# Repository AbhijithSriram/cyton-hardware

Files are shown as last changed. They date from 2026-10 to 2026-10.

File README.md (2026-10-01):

# OpenBCI Cyton — self-fabricated board, complete record

A self-fabricated **OpenBCI Cyton V3 (32-bit)** — ordered from JLCPCB from the open
hardware files, flashed over ICSP, and made wireless with a **Seeed XIAO ESP32C3** bridge
in place of the obsolete RFD22301 radio that was never populated.

This repo is the whole record: the order files, the firmware, the bring-up, every mistake
made getting there, the software stack that records from it, and the EEG it has recorded.

| | |
|---|---|
| **Board** | OpenBCI Cyton V3, PIC32MX250F128B + ADS1299IPAG, 8 channels @ 250 SPS |
| **Firmware** | OpenBCI_32bit_Library v3.1.5, built with `board.beginDebug()` |
| **Link** | Cyton `D11`/`D12` → XIAO ESP32C3 → WiFi TCP `192.168.4.1:3000` → Flask |
| **Proven** | ADS1299 ID `0x3E`, test signal ±3.74 mV (0.3 % error), noise floor ±1 µV, 250 pkt/s with 0 malformed |
| **Recorded** | Real EEG on 2 frontal channels — alpha blocks and motor execution |

**Start here:** [`docs/CYTON_BRINGUP.md`](docs/CYTON_BRINGUP.md) — the full technical
record, fabrication through live streaming. §11 is the troubleshooting catalogue: 13 traps,
each with the symptom that identifies it.

---

## Map

| Folder | Contents |
|---|---|
| `docs/` | The bring-up document. Wiring guides for the [frontal/Muse-comparison montage](docs/WIRING-cyton-muse-athena.md) and for [motor imagery](docs/WIRING-motor-imagery.md). Electrode [research](docs/Electrode_Research.md) and [decision](docs/ELECTRODE_DECISION.md). |
| `hardware/` | What the board was built from: `gerbers/` (the set actually sent out), `bom/` (BOM + JLCPCB CPL), `quotes/` (JLCPCB, Robu, LionCircuits), `component-selection/`, `reference/` (schematic, DesignSpark source, photos). |
| `firmware/cyton/` | The exact sketch flashed to the PIC32 — `DefaultBoard` with the one changed line, `board.beginDebug()` — plus the hex the IDE built. |
| `firmware/bridge/` | `CytonWiFiBridge.ino`, the XIAO ESP32C3 UART↔TCP bridge. Its header comment is the wiring reference. |
| `firmware/images/` | `CytonDebug-with-bootloader.hex` — the merged bootloader + application image on the board right now. |
| `firmware/tools/` | `merge-hex.ps1` (Intel HEX merger with overlap detection), `listen-cyton.ps1` (serial listener that recognises the ADS1299 ID). |
| `software/` | The Flask server and web UI, the CLI client, the cue protocols, a fake bridge for working with no hardware, and `recordings/`. |
| `logs/` | The first serial capture taken off the board. |
| `vendor/`, `mechanical/` | Upstream clones and headset STLs. On disk, **git-ignored**, pinned in [`VENDOR.md`](VENDOR.md). |

## Running it

Join the bridge's WiFi (`CytonBridge`, the XIAO is always `192.168.4.1`), then:

```bash
python software/cyton_server.py
```

Open <http://127.0.0.1:5000>, press **b** to start streaming, and pick a protocol from the
experiment list. Recordings land in `software/recordings/` as CSV with a `phase` column on
every row, plus an `-events.csv` giving each cue onset as an absolute **sample index**.

No hardware attached? Two terminals:

```bash
python software/fake_bridge.py
python software/cyton_server.py --host 127.0.0.1
```

## Electrodes, as currently wired

Two channels of 3M Ag/AgCl ECG gel patches. Electrodes go to the **N** pins — the P side is
already tied to SRB2 internally.

| Patch | Position | PL1 pin | Channel |
|---|---|---:|---|
| 1 | AF7, left forehead | 21 | ch1 (`1N`) |
| 2 | AF8, right forehead | 19 | ch2 (`2N`) |
| 3 | Fpz, centre forehead | 23 | `SRB2` — reference |
| 4 | Mastoid or earlobe | 5 | `BIAS` — not optional |

Channels 3–8 read ±187500 µV because nothing is wired to them. Full detail, skin prep and
test protocol: [`docs/WIRING-cyton-muse-athena.md`](docs/WIRING-cyton-muse-athena.md).

## What is not documented

Honest gaps, listed in `docs/CYTON_BRINGUP.md` §12.4: the **battery and power wiring**
(spec, connector, charging, how SW2's missing switch is bridged), the **physical assembly
record** for the hand-soldered PL1 header and the XIAO hookup, and the **alpha ratio
comparison against the Muse**, which has recordings but no written result.

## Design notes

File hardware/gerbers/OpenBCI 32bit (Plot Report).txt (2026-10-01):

Plot Report
-----------

Report Written:     22:28 Thursday, July 02, 2026
Design Path:        C:\Users\abhij\Desktop\NeuroRehab\OpenBCI\OpenBCI Cyton Designs\OpenBCI 32bit.pcb
Design Title:       
Created:            7/31/2013 8:13:11 AM
Last Saved:         6/20/2017 11:40:16 PM
Editing Time:       116262 min
Units:              thou (precision 0)

Device Settings
===============

Gerber Settings
===============

Gerber Format: RS-274-X
    Leading zero suppression.
    G01 assumed throughout.
    Line termination <*> <CR> <LF>.
    3.5 format absolute inches.

    Format commands defined in Gerber file.
    Aperture table defined in Gerber file.
    Hardware arcs allowed.

Drill Settings
==============

    Excellon Format 2
    Format 3.5 absolute in mm.
    Zero suppression Leading

Plots Output
============

    Plot Job: "C:\Users\abhij\Desktop\NeuroRehab\OpenBCI\OpenBCI Cyton Designs\OpenBCI 32bit.mop"

Gerber Output
=============

C:\Users\abhij\Desktop\NeuroRehab\OpenBCI\OpenBCI Cyton Designs\OpenBCI 32bit - Top Silkscreen.gbr

    Layers:
    ------------------
    Top Silkscreen

    D-Code Shape  (thou)
    -----------------------
    D10    Round 5.00
    D11    Round 3.00
    D12    Round 1.00
    D13    Round 10.00
    D14    Round 8.00
    D15    Round 6.00

Gerber Output
=============

C:\Users\abhij\Desktop\NeuroRehab\OpenBCI\OpenBCI Cyton Designs\OpenBCI 32bit - Top Copper.gbr

    Layers:
    --------------
    Top Copper

    D-Code Shape  (thou)
    ----------------------------------------------
    D10    Round 5.00
    D13    Round 10.00
    D16    Round 15.00
    D17    Round 20.00
    D18    Round 32.00
    D19    Round 30.00
    D70    Round 40.00
    D71    Rectangle 11.81 X 47.24
    D20    Rectangle 11.81 X 47.24  Rotation 90
    D21    Rectangle 24.00 X 24.00
    D22    Square 63.00
    D23    Rectangle 24.00 X 24.00  Rotation 90
    D24    Rectangle 17.00 X 72.00  Rotation 90
    D25    Rectangle 39.40 X 43.30
    D26    Rectangle 39.40 X 43.30  Rotation 90
    D27    Rectangle 55.00 X 71.00
    D28    Rectangle 26.00 X 42.00
    D29    Square 60.00
    D72    Rectangle 12.00 X 20.00  Rotation 90
    D73    Rectangle 12.00 X 20.00
    D74    Rectangle 16.00 X 35.00
    D75    Square 60.00  Rotation 45
    D76    Rectangle 18.00 X 46.00  Rotation 90
    D77    Round 36.00
    D78    Rectangle 39.37 X 42.91

Gerber Output
=============

C:\Users\abhij\Desktop\NeuroRehab\OpenBCI\OpenBCI Cyton Designs\OpenBCI 32bit - Documentation.gbr

    Layers:
    -----------------
    Documentation

    D-Code Shape  (thou)
    -----------------------
    D10    Round 5.00

Gerber Output
=============

C:\Users\abhij\Desktop\NeuroRehab\OpenBCI\OpenBCI Cyton Designs\OpenBCI 32bit - Top Solder Mask.gbr

    Layers:
    -------------------
    Top Solder Mask

    D-Code Shape  (thou)
    ----------------------------------------------
    D79    Round 138.00
    D80    Rectangle 17.81 X 53.24
    D81    Rectangle 17.81 X 53.24  Rotation 90
    D82    Rectangle 30.00 X 30.00
    D83    Square 69.00
    D84    Rectangle 30.00 X 30.00  Rotation 90
    D85    Rectangle 23.00 X 78.00  Rotation 90
    D86    Rectangle 45.40 X 49.30
    D87    Rectangle 45.40 X 49.30  Rotation 90
    D88    Rectangle 61.00 X 77.00
    D89    Rectangle 32.00 X 48.00
    D90    Square 66.00
    D91    Rectangle 18.00 X 26.00  Rotation 90
    D92    Rectangle 18.00 X 26.00
    D93    Rectangle 22.00 X 41.00
    D94    Square 66.00  Rotation 45
    D95    Rectangle 24.00 X 52.00  Rotation 90
    D96    Round 42.00
    D97    Rectangle 45.37 X 48.91

Gerber Output
=============

C:\Users\abhij\Desktop\NeuroRehab\OpenBCI\OpenBCI Cyton Designs\OpenBCI 32bit - Top Paste Mask.gbr

    Layers:
    ------------------
    Top Paste Mask

    D-Code Shape  (thou)
    ----------------------------------------------
    D29    Square 60.00
    D98    Rectangle 8.81 X 44.24
    D99    Rectangle 8.81 X 44.24  Rotation 90
    D100   Rectangle 21.00 X 21.00
    D101   Rectangle 21.00 X 21.00  Rotation 90
    D102   Rectangle 14.00 X 69.00  Rotation 90
    D103   Rectangle 36.40 X 40.30
    D104   Rectangle 36.40 X 40.30  Rotation 90
    D105   Rectangle 52.00 X 68.00
    D106   Rectangle 23.00 X 39.00
    D107   Rectangle 9.00 X 17.00  Rotation 90
    D108   Rectangle 9.00 X 17.00
    D109   Rectangle 13.00 X 32.00
    D110   Rectangle 15.00 X 43.00  Rotation 90
    D111   Rectangle 36.37 X 39.91

Gerber Output
=============

C:\Users\abhij\Desktop\NeuroRehab\OpenBCI\OpenBCI Cyton Designs\OpenBCI 32bit - Layer 2 Copper.gbr

    Layers:
    ------------------
    Layer 2 Copper

    D-Code Shape  (thou)
    -----------------------------------
    D10    Round 5.00
    D13    Round 10.00
    D16    Round 15.00
    D18    Round 32.00
    D29    Square 60.00
    D75    Square 60.00  Rotation 45
    D77    Round 36.00

Gerber Output
=============

C:\Users\abhij\Desktop\NeuroRehab\OpenBCI\OpenBCI Cyton Designs\OpenBCI 32bit - Layer 3 Copper.gbr

    Layers:
    ------------------
    Layer 3 Copper

    D-Code Shape  (thou)
    -----------------------------------
    D10    Round 5.00
    D16    Round 15.00
    D18    Round 32.00
    D29    Square 60.00
    D75    Square 60.00  Rotation 45
    D77    Round 36.00

Gerber Output
=============

C:\Users\abhij\Desktop\NeuroRehab\OpenBCI\OpenBCI Cyton Designs\OpenBCI 32bit - Bottom Copper.gbr

    Layers:
    -----------------
    Bottom Copper

    D-Code Shape  (thou)
    -----------------------------------------------
    D10    Round 5.00
    D13    Round 10.00
    D14    Round 8.00
    D16    Round 15.00
    D17    Round 20.00
    D18    Round 32.00
    D19    Round 30.00
    D70    Round 40.00
    D21    Rectangle 24.00 X 24.00
    D23    Rectangle 24.00 X 24.00  Rotation 90
    D25    Rectangle 39.40 X 43.30
    D26    Rectangle 39.40 X 43.30  Rotation 90
    D29    Square 60.00
    D75    Square 60.00  Rotation 45
    D76    Rectangle 18.00 X 46.00  Rotation 90
    D77    Round 36.00
    D78    Rectangle 39.37 X 42.91
    D112   Rectangle 23.62 X 47.24  Rotation 90
    D113   Rectangle 21.65 X 47.24
    D114   Rectangle 23.62 X 47.24
    D115   Rectangle 39.37 X 42.91  Rotation 90
    D116   Square 63.00  Rotation 45
    D117   Rectangle 10.00 X 27.56
    D118   Rectangle 32.00 X 132.00  Rotation 90
    D119   Rectangle 27.00 X 63.00  Rotation 135
    D120   Rectangle 47.00 X 87.00  Rotation 135
    D121   Rectangle 55.00 X 63.00  Rotation 45
    D122   Rectangle 47.00 X 63.00  Rotation 135
    D123   Rectangle 59.00 X 134.00
    D124   Rectangle 39.00 X 138.00
    D125   Rectangle 28.00 X 59.00  Rotation 90
    D126   Rectangle 32.00 X 39.00
    D127   Rectangle 55.00 X 55.00  Rotation 135

Gerber Output
=============

C:\Users\abhij\Desktop\NeuroRehab\OpenBCI\OpenBCI Cyton Designs\OpenBCI 32bit - Bottom Silkscreen.gbr

    Layers:
    ---------------------
    Bottom Silkscreen

    D-Code Shape  (thou)
    -----------------------
    D10    Round 5.00
    D11    Round 3.00
    D14    Round 8.00
    D15    Round 6.00

Gerber Output
=============

C:\Users\abhij\Desktop\NeuroRehab\OpenBCI\OpenBCI Cyton Designs\OpenBCI 32bit - Bottom Solder Mask.gbr

    Layers:
    ----------------------
    Bottom Solder Mask

    D-Code Shape  (thou)
    -----------------------------------------------
    D79    Round 138.00
    D82    Rectangle 30.00 X 30.00
    D84    Rectangle 30.00 X 30.00  Rotation 90
    D86    Rectangle 45.40 X 49.30
    D87    Rectangle 45.40 X 49.30  Rotation 90
    D90    Square 66.00
    D94    Square 66.00  Rotation 45
    D95    Rectangle 24.00 X 52.00  Rotation 90
    D96    Round 42.00
    D97    Rectangle 45.37 X 48.91
    D128   Rectangle 29.62 X 53.24  Rotation 90
    D129   Rectangle 27.65 X 53.24
    D130   Rectangle 29.62 X 53.24
    D131   Rectangle 45.37 X 48.91  Rotation 90
    D132   Square 69.00  Rotation 45
    D133   Rectangle 16.00 X 33.56
    D134   Rectangle 38.00 X 138.00  Rotation 90
    D135   Rectangle 33.00 X 69.00  Rotation 135
    D136   Rectangle 53.00 X 93.00  Rotation 135
    D137   Rectangle 61.00 X 69.00  Rotation 45
    D138   Rectangle 53.00 X 69.00  Rotation 135
    D139   Rectangle 65.00 X 140.00
    D140   Rectangle 45.00 X 144.00
    D141   Rectangle 34.00 X 65.00  Rotation 90
    D142   Rectangle 38.00 X 45.00
    D143   Rectangle 61.00 X 61.00  Rotation 135

Gerber Output
=============

C:\Users\abhij\Desktop\NeuroRehab\OpenBCI\OpenBCI Cyton Designs\OpenBCI 32bit - Bottom Paste Mask.gbr

    Layers:
    ---------------------
    Bottom Paste Mask

    D-Code Shape  (thou)
    -----------------------------------------------
    D75    Square 60.00  Rotation 45
    D100   Rectangle 21.00 X 21.00
    D101   Rectangle 21.00 X 21.00  Rotation 90
    D103   Rectangle 36.40 X 40.30
    D104   Rectangle 36.40 X 40.30  Rotation 90
    D110   Rectangle 15.00 X 43.00  Rotation 90
    D111   Rectangle 36.37 X 39.91
    D144   Rectangle 20.62 X 44.24  Rotation 90
    D145   Rectangle 18.65 X 44.24
    D146   Rectangle 20.62 X 44.24
    D147   Rectangle 36.37 X 39.91  Rotation 90
    D148   Rectangle 7.00 X 24.56
    D149   Rectangle 29.00 X 129.00  Rotation 90
    D150   Rectangle 24.00 X 60.00  Rotation 135
    D151   Rectangle 44.00 X 84.00  Rotation 135
    D152   Rectangle 52.00 X 60.00  Rotation 45
    D153   Rectangle 44.00 X 60.00  Rotation 135
    D154   Rectangle 56.00 X 131.00
    D155   Rectangle 36.00 X 135.00
    D156   Rectangle 25.00 X 56.00  Rotation 90
    D157   Rectangle 29.00 X 36.00
    D158   Rectangle 52.00 X 52.00  Rotation 135

Gerber Output
=============

C:\Users\abhij\Desktop\NeuroRehab\OpenBCI\OpenBCI Cyton Designs\OpenBCI 32bit - Gerber Drill Data - [Through Hole].gbr

    Layers:
    ------------------
    [Through Hole]

    D-Code Shape  (thou)
    -----------------------
    D159   Round 16.00
    D160   Round 185.00
    D161   Round 35.00
    D162   Round 36.00

NC Drill Output
===============

C:\Users\abhij\Desktop\NeuroRehab\OpenBCI\OpenBCI Cyton Designs\OpenBCI 32bit - NC Drill Data - [Through Hole].drl

    Output:
    ---------------------------
    Plated Round Drill Holes
    Plated Slots

    Tool  Size           Count   ID
    --------------------------------------
    T001  0.01600 inches 105   A
    T002  0.03500 inches 44    C
    --------------------------------------
    Total                149
    --------------------------------------

C:\Users\abhij\Desktop\NeuroRehab\OpenBCI\OpenBCI Cyton Designs\OpenBCI 32bit - NC Drill Data - [Through Hole] (Unplated).drl

    Output:
    -----------------------------
    Unplated Round Drill Holes
    Unplated Slots

    Tool  Size           Count   ID
    --------------------------------------
    T001  0.03500 inches 2     D
    T002  0.03600 inches 2     E
    T003  0.18500 inches 4     B
    --------------------------------------
    Total                8
    --------------------------------------

Gerber Output
=============

C:\Users\abhij\Desktop\NeuroRehab\OpenBCI\OpenBCI Cyton Designs\OpenBCI 32bit - Drill Ident Drawing - [Through Hole].gbr

    Layers:
    ------------------
    [Through Hole]

Drill Ident Drawing
===================

    Drill Plated Size Shape ID
    -----------------------------------
    16    Y      100  Round A
    185          100  Round B
    35    Y      100  Round C
    35           100  Round D
    36           100  Round E

    D-Code Shape  (thou)
    -----------------------
    D10    Round 5.00
    D163   Round 100.00

Gerber Output
=============

C:\Users\abhij\Desktop\NeuroRehab\OpenBCI\OpenBCI Cyton Designs\OpenBCI 32bit - Board Outline.gbr

    Layers:
    ------------------
    Board Outlines

    D-Code Shape  (thou)
    -----------------------
    D10    Round 5.00

End Of Report.

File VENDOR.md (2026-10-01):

# Upstream dependencies

Four upstream trees are used by this project. All are public, all are pinned to a known
commit, and none of them are tracked here — `vendor/` and `mechanical/` are git-ignored, so
a clone of this repo is small and contains only work that cannot be downloaded again.

Everything in those trees that was **not** upstream — the regenerated Gerbers, the JLCPCB
BOM and CPL, the quotes, the component-selection PDFs — was lifted out into `hardware/`
and **is** tracked here. Nothing irreplaceable sits behind a `.gitignore`.

| Path on disk | Upstream | Pinned at | Why it is kept |
|---|---|---|---|
| `vendor/openbci-v3-hardware/` | <https://github.com/OpenBCI/V3_Hardware_Design_Files> | `6bce559` (2023-02-06) | Schematic, PCB, upstream Gerbers and BOM/CPL. Two files locally modified — see below |
| `vendor/openbci-v3-hardware/OpenBCI_Cyton_Library/` | <https://github.com/OpenBCI/OpenBCI_Cyton_Library> | `24e1c42` (2025-07-24) | v3.1.5 — the firmware source that was compiled and flashed |
| `vendor/openbci-v3-hardware/PIC32-avrdude-bootloader/` | <https://github.com/chipKIT32/PIC32-avrdude-bootloader> | `95cf5d9` (2024-02-08) | `BootloadersCurrent-hex/UDB32_MX2_DIP.hex` is the bootloader half of the flashed image |
| `mechanical/ultracortex-upstream/` | <https://github.com/OpenBCI/Ultracortex> | `338b52b` (2022-09-29) | Headset mechanicals. Only `Mark_IV` is checked out; the clone's index is empty |

`vendor/PIC32-avrdude-bootloader-master/` plus its zip is an older, separate download of
the same bootloader. Kept because the flashing was actually done from that copy.

`mechanical/a1-mini-prints/` is **not** upstream — those are the Bambu A1 Mini plates and
the Cyton case that were printed. 2.6 MB. Git-ignored with the rest of `mechanical/`; to
track them instead, drop the `/mechanical/` line from `.gitignore` and re-add.

## Restoring any of them

```bash
# hardware design files (the parent tree)
git clone https://github.com/OpenBCI/V3_Hardware_Design_Files.git vendor/openbci-v3-hardware
git -C vendor/openbci-v3-hardware checkout 6bce559

# Cyton firmware library, nested inside it (and installed for the IDE at
# Documents/Arduino/libraries/OpenBCI_32bit_Library)
git clone https://github.com/OpenBCI/OpenBCI_Cyton_Library.git \
          vendor/openbci-v3-hardware/OpenBCI_Cyton_Library
git -C vendor/openbci-v3-hardware/OpenBCI_Cyton_Library checkout 24e1c42

# chipKIT bootloader
git clone https://github.com/chipKIT32/PIC32-avrdude-bootloader.git \
          vendor/openbci-v3-hardware/PIC32-avrdude-bootloader
git -C vendor/openbci-v3-hardware/PIC32-avrdude-bootloader checkout 95cf5d9

# headset mechanicals
git clone https://github.com/OpenBCI/Ultracortex.git mechanical/ultracortex-upstream
git -C mechanical/ultracortex-upstream checkout 338b52b
```

The existing Ultracortex clone has a populated HEAD against an empty index, so it looks
like 686 staged deletions and only `Mark_IV` is on disk. Its pack holds every revision —
`Mark_1`, `Mark_2`, `Mark_3`, `Mark_III_Nova`, `Mark_III_Nova_REVISED`, `Mark_IV` — and one
command brings them all back without the network:

```bash
git -C mechanical/ultracortex-upstream reset --hard HEAD
```

That is what made it safe to delete `Ultracortex2/` (502 MB, a duplicate `.git` at the same
commit), `Ultracortex_Downloaded/` (175 MB, `Mark_1`–`Mark_3`) and `Ultracortex.zip`
(79 MB) on 1 October 2026. 756 MB freed, nothing lost.

## Local modifications to the hardware design files

Two tracked files in `vendor/openbci-v3-hardware/` differ from upstream. Both are copied
into `hardware/`, so a fresh clone of upstream plus this repo reproduces what was ordered:

| File in the clone | Change | Tracked copy here |
|---|---|---|
| `OpenBCI Cyton Designs/OpenBCI 32bit.pcb` | Re-saved from DesignSpark (360 KB → 395 KB) | `hardware/reference/OpenBCI 32bit.pcb` |
| `OBCI_Cyton_Plots/OBCI_V4_C (Component Positions CSV).csv` | Header rewritten to JLCPCB CPL format: `Name,Component,Side,Centre X,Centre Y,Rotation` → `Designator,Val,Layer,Mid X,Mid Y,Rotation` | `hardware/bom/CPL-OBCI_V4_C-jlcpcb-format.csv` |

## Toolchain versions

Not vendored, but the versions that worked, for the record:

| Tool | Version | Note |
|---|---|---|
| Arduino IDE | 2.x | chipKIT core for the Cyton, ESP32 core for the XIAO |
| chipKIT core | 2.1.0 | Already ships `Board_Defs.h` with 11/12 — do **not** apply the library's stale edit instruction |
| Board (Cyton) | chipKIT → OpenBCI 32 | variant `chipKIT.pic32.openbci` |
| Board (bridge) | XIAO_ESP32C3 | **USB CDC On Boot: ENABLED** — not optional |
| MPLAB X IPE | v5.35 | Flashing the merged hex with a PICkit 3.5 |

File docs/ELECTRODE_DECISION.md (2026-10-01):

# Electrode & Headset Decision — NeuroRehab

**Working document for the headset design. Two viable paths, laid out with costs, setup, and the reasoning behind each.**

Context: the Cyton is built and streaming (see `CYTON_BRINGUP.md`). The remaining hardware question is what touches the scalp. This is written as a decision aid, not a conclusion — the recommendation shifts depending on whether the target is a research rig or a patient-facing rehab product.

> 💰 All prices are **estimates in INR**, current as of writing. OpenBCI prices are from their store; "generic" prices assume AliExpress / IndiaMART sourcing. **Add shipping and customs for anything imported** — a real factor, and the same one that drove the decision to fabricate the Cyton at JLCPCB rather than buy it.

---

## 1. The montage is already fixed

This is not an open question. From `Neuro-Rehab-git/src/run_ablation.sh`:

```bash
# Simulates testing 8-channel consumer EEG hardware (e.g. ADS1299)
CHANNELS="C3 Cz C4 FC3 FC4 CP3 CP4"
```

The same seven appear in `cache_foundation.py` and `cache_openbmi.py`. A 5-channel subset (`C3, Cz, C4, CP3, CP4`) is used in `train_physionet_5ch.py` with weights at `Models/neurorehab_bci_5ch.pth`.

**Requirement: 7 scalp electrodes + 1 reference + 1 bias = 9 total.** The Cyton has 8 differential inputs, so 7 channels used, 1 spare.

Geometrically these form a **3×3 grid centred on Cz**, roughly 12 cm ear-to-ear and 8 cm front-to-back:

```
        FC3    ·    FC4
         C3   Cz    C4          all within the central third
        CP3    ·    CP4          of the scalp
```

This compactness matters later — see §5.

---

## 2. What the benchmark already tells us

From `Neuro-Rehab-git/README.md`:

| Dataset | Channels | Best model | Accuracy |
|---|---:|---|---:|
| **2B** | **3** (C3/Cz/C4) | Conformer (transfer) | **78.89%** |
| 2A | 22 | EEGNet | 78.86% |

**Three well-placed electrodes matched twenty-two.** Channel *count* is not the bottleneck, so no headset choice fails on coverage grounds. What the same table shows is where accuracy actually leaks:

- **FBCSP collapsed to 52.95%** at 3 channels — near chance. Classical methods need spatial redundancy.
- **EEGNet fell 78.86% → 70.91%** when channels were cut ("struggles when deprived of spatial electrodes").
- **Transfer learning recovered it** — Conformer, Deep4 and Inception each gained 4–6 points at low density.

> ⚠️ **Architecture note:** `Models/neurorehab_bci_5ch_eegnet.txt` exists. By this benchmark, EEGNet is the *weakest* architecture in exactly the low-channel regime the Cyton puts you in. Conformer-with-transfer is the strongest. Worth revisiting before deployment.

Since coverage is solved, the headset decision reduces to two variables: **placement repeatability** and **contact impedance**.

---

## 3. Option A — Wet: textile 10-20 cap + gold cup electrodes

The research-standard approach.

### 3.1 Bill of materials

| Item | Qty | OpenBCI | Generic | Notes |
|---|---:|---:|---:|---|
| Textile 10-20 EEG cap | 1 | — | ₹2,000–5,000 | **Must have 10-10 markings** — FC3/FC4/CP3/CP4 are not in the 19-site 10-20 set |
| Gold cup electrodes | 10 | ₹4,400 | ₹1,500–3,000 | ₹150–300 each generic vs ~₹440 from OpenBCI |
| Ten20 conductive paste (228 g) | 1 | — | ₹1,200–2,000 | The actual conductor |
| NuPrep abrasive gel (114 g) | 1 | — | ₹700–1,200 | Skin prep — matters more than people expect |
| Blunt-tip syringes | few | — | ₹300 | For getting paste under hair |
| Measuring tape + skin pencil | 1 | — | ₹200 | For nasion–inion measurement |
| Gauze, alcohol wipes | — | — | ₹500 | Consumable |
| **Total** | | | **₹6,400–12,200** | |

**Not needed:** OpenBCI's ₹3,900 *Header Pin to Touch Proof Adapter*. That's for DIN 1.5 mm electrodes; gold cups terminating in header pins plug into the Cyton directly.

### 3.2 Setup procedure (~15–20 min per session)

1. Measure **nasion → inion** and **left preauricular → right preauricular**. Cz is at 50% of both.
2. Select cap size by head circumference; seat it with the cap's Cz marker on the measured Cz.
3. For each of 9 sites: part the hair, abrade lightly with NuPrep on a cotton bud.
4. Fill the gold cup with Ten20, press onto the scalp through the cap hole, seat until the paste bridges.
5. Reference and bias go on the **mastoids or earlobes** (no hair, easy contact).
6. Verify impedance on every channel before starting.
7. Afterwards: patient washes their hair; cap is washed and dried.

### 3.3 Why it's the strongest signal

- **Impedance in single-digit kΩ** versus hundreds of kΩ dry. Mu (8–13 Hz) and beta (13–30 Hz) ERD are small effects, and the Cyton's ±1 µV noise floor is only meaningful if the electrode isn't the dominant noise source.
- **Precise, repeatable placement.** Positions are *measured* from anatomical landmarks, so they're the same today and next month. This is what makes a model trained once transfer across sessions.
- **Matches the training data.** PhysioNet and OpenBMI were recorded at exact 10-10 coordinates. Placement error is distribution shift.
- **Motion tolerance.** Paste maintains contact through small head movements.

### 3.4 Why it fails as a rehab product

| Problem | Consequence |
|---|---|
| 15–20 min setup, every session | A rehab programme is *many* sessions. This is a dropout cause, not an inconvenience. |
| Patient leaves with gel in their hair | Dignity issue. Requires a shower after every session. |
| Cap must be washed and dried between patients | Kills clinic turnaround; you'd need several caps in rotation. |
| Requires a trained operator | Not something a caregiver does at home. |
| Long static sitting during application | Hard for hemiparetic patients. |

**Verdict: correct for collecting training data and for validation. Wrong for the product.**

---

## 4. Option B — Dry: comb electrodes

### 4.1 Why this is right for neurorehab

The properties that make wet electrodes better in a lab are precisely what make them unusable in a clinic:

| | Wet | Dry |
|---|---|---|
| Setup per session | 15–20 min | **~2–3 min** |
| Patient leaves with | Gel in hair | **Nothing** |
| Between patients | Wash + dry cap | **Alcohol wipe** |
| Who can apply it | Trained operator | **A caregiver, after a demo** |
| Repeat sessions over weeks | High friction | **Low friction** |

For stroke rehabilitation — repeated sessions over weeks or months, patients with hemiparesis and possible cognitive load, applied by clinic staff or family — **ease of donning dominates absolute signal quality.**

### 4.2 What makes it actually work: per-session calibration

The usual objection to dry electrodes is that placement and impedance vary between sessions, so a model trained once doesn't transfer.

**The pipeline already doesn't assume that.** `benchmark_results_final.csv` contains `n_calib_trials` of 10/15/20/27 and a full `3_adaptation` phase. Per-subject calibration is already the architecture.

A short calibration at the start of each session absorbs that day's placement and contact quality into the model. Session-to-session variability stops being an engineering problem and becomes a two-minute step the patient does while getting settled.

> **Dry electrodes + per-session calibration is a legitimate product architecture.** It costs a few accuracy points and buys a device people will actually use.

### 4.3 Bill of materials

| Item | Qty | OpenBCI | Generic / DIY | Notes |
|---|---:|---:|---:|---|
| Dry comb electrodes | 9 + spares | ₹4,900 (30-pack) | — | ≈₹163 each — reasonable. Designed for the Ultracortex node holder |
| *or* EEG Snap Electrodes (metal comb) | 5-pack | ₹3,000 | — | Needs snap cables (₹5,400) — **more expensive overall** |
| Ear-clip electrodes (ref + bias) | 2 | — | ₹500–1,500 | Earlobes/mastoids have no hair — clips beat combs here |
| Octabolts + electrode holders | 9 | — | **3D printed** | STLs already in `Ultracortex/.../M4 Hardware/` |
| Compression springs | 9 | — | ₹300 | For the spring-loaded node assembly |
| M3 screws / nuts / heat inserts | — | — | ₹400 | |
| Filament (PETG or PLA) | ~150 g | — | ₹300 | Band + holders |
| Silicone-jacketed wire, 26–28 AWG | ~5 m | — | ₹500 | Electrode → Cyton |
| Dupont / header connectors | — | — | ₹300 | To PL1 |
| 13×2 header for PL1 | 1 | — | ₹100 | ⚠️ **Count the pads first** — README says 11×2, CPL says `26WDP` |
| **Total** | | | **≈₹7,300–9,000** | |

**Comparable up-front cost to wet.** The real difference is **per-session consumables (zero vs paste + prep gel) and time (2 min vs 20 min).** Over a rehab programme, that's the entire argument.

### 4.4 Setup procedure (~2–3 min per session)

1. Select band size / adjust the sliding mechanism.
2. Seat using ear-canal and nasion landmarks.
3. Tighten each Octabolt until the contact indicator (§6) goes green.
4. Run the calibration block.
5. Afterwards: wipe electrodes with alcohol.

---

## 5. The design insight: build a band, not a cage

The Ultracortex Mark IV is a full geodesic head frame reaching 35 positions from Fp to O. **You use none of the frontal, temporal, or occipital structure** — your 7 sites sit in a compact 3×3 grid over the vertex (§1).

You are carrying a whole-head exoskeleton to instrument a strip.

**Proposal: a sensorimotor band.** An arc over the vertex from ear to ear, with short forward and rearward arms reaching the FC and CP rows — roughly an "H" or cross shape.

| Benefit | Why |
|---|---|
| **Faster donning** | One axis to align, not a cage to seat |
| **Better repeatability** | Anchor on **ear canals** (coronal line through Cz) and **nasion–inion** (A–P). Those are the same landmarks a 10-20 measurement uses — arguably *more* repeatable than a lattice hole that happens to land near FC3 |
| **Lighter, less clinical** | A band reads as a headset; a cage reads as an experiment. Matters for patient acceptance |
| **Fewer sizes to stock** | The DevKit ships five frames (`08mm_Small` → `28mm_Large`). A shorter arc tolerates far more head-size variation with one adjustment mechanism |
| **Reuses existing parts** | `M4_Hardware_09_Octabolt.STL`, `M4_Hardware_09_Eholder.STL`, `M4_Hardware_07d_Node_4d.STL` are already in the Ultracortex checkout. Keep the spring-loaded comb assembly, drop the cage |

### 5.1 Caveat on Ultracortex placement accuracy

The Mark IV is a **lattice, not a 10-20 map**. The README says the frame is *"based on an average of many heads"*; you screw nodes into whichever holes land near your target. So a Mark IV position is *approximately* FC3, varying with head size and re-seating.

For C3/C4 mu-ERD that's survivable — motor cortex is a broad strip. But it isn't repeatable between sessions, which is exactly what per-session calibration exists to absorb. A landmark-referenced band reduces the problem at source rather than relying on software to fix it.

---

## 6. Contact quality becomes a product requirement

With dry electrodes, **bad contact is the failure mode**, and the clinician must see it *before* the session, not after.

Both halves already exist:

- **Firmware:** `configureLeadOffDetection(LOFF_MAG_6NA, LOFF_FREQ_31p2HZ)` runs inside `boardReset()` at every boot. The ADS1299 impedance measurement is already configured.
- **Client:** `is_railed()` in `cyton_client.py` flags `±187500 µV` — exactly what a detached or badly-seated electrode looks like.

**To build:** a per-electrode contact indicator in the web UI — green / amber / red per channel, live during donning. The clinician adjusts each Octabolt until all seven go green, then starts.

That single feature is what separates "dry electrodes work in the lab" from "dry electrodes work in a clinic."

---

## 7. Residual risks

| Risk | Notes | How to retire it |
|---|---|---|
| **Thick or dense hair** | Where dry combs genuinely struggle. No software fix. | Test early with hair types representative of actual patients — not just yours. Fallback is a little saline on the comb tips (towels off, no shower) |
| **Comfort over 30–60 min** | Spring-loaded combs press into the scalp. Fine for 10 min, potentially sore for an hour | Measure with real session lengths before finalising the mechanical design |
| **Hemiparetic patients** | May not tolerate certain head positions or be able to assist | Design for one-handed application by a caregiver |
| **Accuracy delta vs wet** | Unquantified for this hardware | Run the same subject through both — that comparison is publishable and directly answers the question |

---

## 8. Summary

| | Wet cap | Dry band |
|---|---|---|
| Up-front cost | ₹6,400–12,200 | ₹7,300–9,000 |
| Per-session consumables | Paste + prep gel | **None** |
| Setup time | 15–20 min | **2–3 min** |
| Placement repeatability | **Excellent** (measured) | Good (landmark-referenced band) |
| Impedance | **Single-digit kΩ** | Hundreds of kΩ |
| Clinic turnaround | Poor | **Excellent** |
| Patient acceptance | Poor | **Good** |
| Best for | Training data, validation, the wet-vs-dry comparison | **The product** |

**Recommendation: build the dry band for the product; keep a wet cap for collecting ground-truth training data and for measuring what dry costs you.** They are not competing options — the wet setup is the instrument you use to validate the dry one.

---

## 9. Open questions for brainstorming

1. Is the reference on **mastoid, earlobe, or Cz**? Affects both the band geometry and how the montage compares to the training data.
2. Does calibration happen **every session**, or only when contact quality degrades? Changes the patient experience meaningfully.
3. **One band size with a wide adjustment range, or two?** Affects moulding cost later.
4. Does the Cyton mount **on the band** (weight on the head) or **clip to clothing** (cable strain)?
5. Should the contact indicator be **on the device** (an LED strip the clinician can see while adjusting) rather than only in the browser?
6. Is the target **clinic-only**, or eventually **home use**? Home use raises the bar on donning simplicity considerably.
7. Retrain on **Conformer + transfer** rather than EEGNet before deployment? §2 suggests ~8 recoverable points.

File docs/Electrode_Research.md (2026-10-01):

# Domestic Indian Sourcing Guide: EEG Electrodes, Consumables & DIY Components for an ADS1299 Motor-Imagery BCI

## TL;DR
- Nearly everything needed can be sourced domestically within India — gold cup electrodes, ear clips, conductive paste, skin prep, ECG electrodes, wire, connectors, and pogo pins are all available from Indian sellers (pan-India shipping) or Chennai-based distributors, at prices well below the OpenBCI benchmarks.
- The hardest item is the multi-prong "dry comb" electrode — no true OpenBCI-style comb electrode is made or resold domestically. Best domestic option: a single-spike dry electrode from Fab.to.Lab, or DIY pogo-pin fabrication.
- For patient-contact use in a stroke-rehab BCI, prefer verified-material wet electrodes (gold/Ag-AgCl cup + paste) over DIY pogo pins, whose nickel underplate cannot be verified from Indian retailer listings — a genuine allergen-safety concern.

Every claim below is linked to its source listing where I have one. Where I could not find or re-capture a stable product URL, I've said so explicitly rather than presenting an unverified guess as fact.

---

## PRIORITY 1 — Electrodes

### 1. Dry comb EEG electrodes (multi-prong, hair-parting) — HARDEST ITEM
**Status: no domestic multi-prong comb electrode found.**

- **Benchmark for comparison:** OpenBCI's ["Dry EEG Comb Electrodes (Pack of 30)"](https://shop.openbci.com/products/dry-eeg-comb-electrodes) — $49.99 for 30 (~$1.67/electrode), silver-then-chlorided 5mm prongs. This is the multi-finger comb type you're trying to replace domestically.
- **Closest domestic ready-made item:** [Fab.to.Lab — "Disposable/Reusable Longer Spike dry EEG Electrode TDE 210 – 5mm"](https://www.fabtolab.com/fri-disposable-reusable-dry-eeg-electrode-tde-210-emg-ecg-eog-5mm) (Bangalore). Listed at ₹400/unit at qty 1, with volume breaks shown on the page (5+ → ₹125 ea, 10+ → ₹95 ea, 50+ → ₹80 ea). **This is a single 5mm spike, not a multi-prong comb** — one point of contact per electrode, not several fingers. The listing does not state electrode coating material (Ag/AgCl vs. stainless vs. gold) — unverified on the page itself.
- **Adjacent domestic product (not a comb, for context):** [Upside Down Labs — "Gold cup electrodes (Pack of 10)"](https://store.upsidedownlabs.tech/product/gold-cup-electrodes-pack-of-10/) and their [BioAmp EXG Pill kit on Amazon.in](https://www.amazon.in/Explorer-Neuroscience-Upside-Down-Labs/dp/B0B29CCPQB), which states it ships with a "dry electrode based EEG Band." Upside Down Labs is an Indian neurotech hardware company, so worth watching, but this is a fabric-band dry electrode, not a comb.
- **DIY fallback, technically documented:** [NCBI/PMC — "3D Printed Dry EEG Electrodes"](https://www.ncbi.nlm.nih.gov/pmc/articles/PMC5087423/) describes the exact 3D-printed-base-plus-conductive-pin construction method you're planning, with electrical performance data — worth reading before finalizing pin geometry.

**Assessment:** I did not find a single Indian manufacturer or reseller of a true multi-prong Ag/AgCl comb electrode across IndiaMART, TradeIndia, Amazon.in, or Indian neurotech stores. This is a negative result — inherently less certain than a positive one — so treat it as "not found in this search," not an absolute guarantee none exists.

### 2. Gold cup EEG electrodes (reusable, ~10mm cup, with lead wire)

| Supplier | Price | Link |
|---|---|---|
| Paul Medical Systems (Chennai) | ₹3,300/piece | [IndiaMART listing](https://www.indiamart.com/proddetail/eeg-electrodes-gold-cup-eeg-electrodes-eeg-disc-electrode-eeg-cup-electrodes-19125339833.html) |
| SS Medsys (New Delhi) | ₹2,200/piece | [IndiaMART listing](https://www.indiamart.com/proddetail/gold-cup-electrodes-20466577188.html) |
| Rama Industries (Mohali) | ₹4,500/set | [IndiaMART listing](https://www.indiamart.com/proddetail/eeg-cup-electrode-gold-plated-22313693655.html) |
| Unique Medical Systems (Mohali) | ₹2,500/set, **MOQ 25 electrodes** | [IndiaMART listing](https://www.indiamart.com/proddetail/eeg-electrode-gold-plated-15036018662.html) |
| Bionen (distributor, Pune) | ₹1,500/piece | [IndiaMART listing](https://www.indiamart.com/proddetail/gold-plated-eeg-electrodes-21496130662.html) |

**Connector note:** these ship with standard clinical EEG lead wires (often 1.5mm DIN touch-proof plugs); none of the listings mention Dupont/header-pin-compatible leads, so budget time to terminate/adapt the free end yourself.

**Wear caveat:** OpenBCI's own product page for their gold cup electrodes notes the electrode should be retired once the gold plating is visibly worn through, because the exposed base metal introduces galvanic noise. The same physical principle applies to any gold-plated cup regardless of manufacturer — treat these as a consumable.

### 3. Ear clip electrodes (reference/bias on earlobe/mastoid)
- I found a reference to AdInstruments South Asia India ear clip electrodes (silver, 9.5mm, 190cm leads) during search, but **could not re-capture a stable direct product URL with a confirmed price** in this pass — flagging as unverified rather than asserting a link I can't stand behind.
- Better path: message the Paul Medical Systems or SS Medsys IndiaMART listings above directly (both have "get best price" contact forms) and ask whether ear-clip leads are sold alongside their cup electrode sets — several sellers in this space bundle both but don't itemize ear clips separately on the public listing.

### 4. Disposable Ag/AgCl ECG electrodes (proposed for reference + bias positions)
- I have directional information (Chennai suppliers Micro Med Charts Mfg. Co. and Growell Technomed were named in search results at roughly ₹4–6/electrode), **but I did not retain checkable product URLs for either during this pass.** I'm not going to present those as clickable links since I can't verify them right now.
- What I can point you to directly: search "disposable ECG electrodes" on [Amazon.in](https://www.amazon.in) — bulk hydrogel Ag/AgCl electrode packs (50–100 count) are a well-established, high-turnover product category there, typically ₹3–5/electrode in bulk. I'd rather send you to search live listings than give you a specific link I can't verify is still active.

**Technical assessment (my own reasoning, not sourced from search):** Disposable Ag/AgCl ECG electrodes are well suited to the reference/bias mastoid positions. Ag/AgCl has a lower and more stable half-cell potential than gold, which is why it's the standard EEG reference material clinically; the pre-gelled adhesive gives good, stable impedance on hairless skin; and single-use is actually convenient for a reference site that needs replacing between sessions. Main practical gap: you'll need a snap-to-wire adapter, which isn't included with these.

---

## PRIORITY 2 — Consumables

### 5. Ten20 conductive paste

| Supplier | Price | Link |
|---|---|---|
| Paul Medical Systems (Chennai) | ₹1,400/packet | [IndiaMART listing](https://www.indiamart.com/proddetail/ten20-eeg-conductive-paste-16249115288.html) |
| Growell Technomed (Chennai) | Price on inquiry | [Growell Technomed product page](https://www.growelltechnomed.in/ten20-eeg-conductive-paste.htm) |
| Distributor, New Delhi | ₹1,500/piece | [IndiaMART listing](https://www.indiamart.com/proddetail/ten20-conductive-neurodiagnostic-electrode-paste-15297336988.html) |
| Distributor, Thiruvananthapuram | ₹1,300 | [Exporters India listing](https://www.exportersindia.com/product-detail/weaver-ten20-conductive-eeg-paste-6147903.htm) |
| Sonika Mediequip (Vadodara) | ₹1,850 | [TradeIndia listing](https://www.tradeindia.com/products/ten20-conductive-eeg-paste-c1753674.html) |
| Aditya Enterprise (Mumbai) | Price on inquiry | [Aditya Enterprise product page](https://www.aditya-enterprise.com/ten20-conductive-paste.html) |

Six independent listings, prices clustering ₹1,300–1,850 — good confidence in both availability and price range.

### 6. NuPrep abrasive skin prep gel

| Supplier | Price | Link |
|---|---|---|
| Paul Medical Systems (Chennai) | ₹1,200 | [Exporters India listing](https://www.exportersindia.com/product-detail/nuprep-skin-prep-gel-2791154495.htm) |
| Distributor, New Delhi (114g tube) | ₹1,200 | [IndiaMART listing](https://www.indiamart.com/proddetail/nuprep-skin-gel-114gms-tube-3088712033.html) |
| Distributor, Hyderabad (100g) | ₹1,100 | [IndiaMART listing](https://www.indiamart.com/proddetail/nuprep-skin-prep-gel-2854058023748.html) |
| RespBuy (online, pan-India) | Listed by pack size | [RespBuy product page](https://respbuy.com/product/weaver-nuprep-skin-preparation-gel-114-gms/) |
| Kardio Surgicare (New Delhi) | Price on inquiry | [Kardio Surgicare product page](https://www.kardiosurgicare.com/skin-preparing-gel.html) |

Same confidence level as Ten20 — multiple independent, consistent listings.

---

## PRIORITY 3 — DIY dry electrode build components

### 7. Gold-plated spring-loaded pogo pins / spring test probes

| Supplier | Product | Price | Link |
|---|---|---|---|
| Robokits India | Spring Test Probe Pogo Pin P75-E2 (MOQ 10pcs) | ₹21/pin | [Robokits product page](https://robokits.co.in/components/cables-connectors/spring-test-probe-pogo-pin-p75-e2-moq-10pcs) |
| Probots | P75-D2 Pogo Pin, round/crown head, PCB testing | ~₹30/pin | [Probots product page](https://probots.co.in/p75-d2-pogo-pin-with-crown-head-for-pcb-testing.html) |
| iFuture Technology | PL75-B1, 0.7mm tip, 16mm length | Priced on page | [iFuture Technology product page](https://ifuturetech.org/product/pl75-b1-0-7mm-tip-16mm-pogo-spring-test-probe-pin/) |

**Plating/nickel flag — the most important safety finding in this document.** Two independent electronics-industry sources describe how these commodity pins are actually constructed:
- [Alibaba's buying guide, "How to Choose Gold Plated Spring Probe Pins"](https://electronics.alibaba.com/buyingguides/gold-plated-spring-probe-pin-guide-what-you-actually-need) — describes the standard build as a thin gold flash over a nickel underplate over a brass or beryllium-copper barrel, presented as the *normal* spec, not an exception.
- [Metabee's "What is a Pogo Pin?" guide](https://metabee.com/blog/post/what-is-a-pogo-pin-the-comprehensive-guide-to-spring-loaded-connectors) — confirms the same gold-over-nickel-over-base-metal layering as conventional construction.

None of the three Indian retailer pages above (Robokits, Probots, iFuture) publish a plating-thickness spec or state whether their specific SKU includes a nickel barrier — I checked each page directly and this information is simply absent, so I can describe the industry-standard construction from the sources above but cannot verify the exact stack per SKU.

On the health side: nickel being a very common contact allergen is something I know from general biomedical background rather than a source I pulled in this search pass — if this becomes a hard design constraint, I'd suggest looking up current dermatology patch-test prevalence data directly rather than relying on my unsourced recollection here.

**Practical implication:** because the gold flash on commodity pins is typically sub-micron, repeated scalp contact and cleaning could eventually expose the nickel layer underneath. For a device intended for stroke patients (not just yourself), this pushes toward wet gold/Ag-AgCl cup electrodes (Priority 1, item 2) as the primary electrode, with pogo pins reserved for bench-testing/non-patient-contact use unless you find a pin with a documented nickel-free or heavy-gold spec.

### 8. Silver conductive paint / silver plating solution
- MG Chemicals silver conductive paint (842-series) appeared in search results as available on Amazon.in, but **I was not able to re-capture a stable direct product URL with confirmed current price/stock.** Search "MG Chemicals Silver Print 842" on [Amazon.in](https://www.amazon.in) to check current listings.
- **Unsourced assessment of my own:** conductive silver paint is formulated for EMI shielding/PCB repair, not biopotential sensing — it isn't chlorided into Ag/AgCl and its binder resin isn't a characterized biocompatible material. Treat as an experimental route requiring your own safety verification, not a recommended default.

---

## PRIORITY 4 — Interconnect

### 9. Silicone-jacketed stranded wire, 26–28 AWG
Robu.in stocks ultra-flexible silicone-jacketed hookup wire in the 26 AWG range, by color and in multi-color kits. I could not capture one stable product URL in this pass — search "silicone wire 26AWG" directly on [Robu.in](https://robu.in), since these SKUs rotate.

### 10. Dupont connectors / 0.1" headers + crimp tool
- Robu.in carries Dupont connector kits (search "Dupont connector kit" on [Robu.in](https://robu.in)).
- Amazon.in carries crimping-tool + Dupont-connector combo kits (search "Dupont crimping tool kit" on [Amazon.in](https://www.amazon.in)).
- No individually checkable URLs retained for this pass — treat as directionally correct, re-search before ordering.

### 11. 13×2 (26-pin) dual-row 0.1" male header
- Cheapest reliable route: buy a full 2×40 breakable dual-row header strip from Robu.in and snap it to 2×13 yourself — completely standard practice, doesn't require finding an exact pre-made pin count.
- Amazon.in also carries pre-made 2×13 box headers/shrouded IDC headers from third-party sellers (search "26 pin 2.54mm box header" on [Amazon.in](https://www.amazon.in)).
- No individual product URLs retained here — this is a low-risk, commodity item, so search fresh at time of purchase rather than relying on a link that may be stale.

---

## PRIORITY 5 — EEG cap (optional)

### 12. Textile EEG cap with 10-10 markings (FC/CP positions)
No Indian-manufactured cap with extended 10-10 markings (including FC3/FC4, CP3/CP4) was found. IndiaMART/TradeIndia "EEG cap" listings found during search were standard 19-site 10-20 caps, which do not include your FC/CP positions. Extended 10-10 caps exist from international manufacturers (e.g., Electro-Cap, BESDATA), but importing reintroduces the customs problem you're trying to avoid.

**Recommendation:** skip the cap. Measure your 7 sites directly using the standard 10-10 measurement procedure (nasion–inion and tragus–tragus percentage method) and hold cup electrodes with Ten20 paste under a simple elastic net or medical wrap. Cheaper and fully domestic, at the cost of re-measuring positions each session.

---

## Summary Table — DIY domestic cost vs. OpenBCI benchmark

| Item | OpenBCI benchmark | Best domestic option | Domestic price (INR) | Link confidence |
|---|---|---|---|---|
| Dry comb electrodes (30) | ₹4,900 | Fab.to.Lab spike, 7 units at ₹95 ea | ~₹665 | Linked, verified page |
| Gold cup electrodes (10) | ₹4,400 | Paul Medical Systems / SS Medsys | ₹2,200–4,500/set | Linked, verified pages |
| Snap electrode cables | ₹5,400 | DIY Dupont + wire | ~₹1,500 (est.) | Not individually linked — re-search at purchase |
| EEG snap electrodes (5) | ₹3,000 | Disposable Ag/AgCl ECG, 100-pack | ~₹300–400 (est.) | Directional only — not link-verified |
| Header→touch-proof adapter | ₹3,900 | Cut leads + Dupont crimp | ~₹500 (est.) | Not individually linked |
| Ten20 paste | add-on | Paul Medical Systems, Chennai | ₹1,400 | Linked, verified page |
| NuPrep gel | add-on | Paul Medical Systems, Chennai | ₹1,200 | Linked, verified page |
| **Approx. total** | **~₹21,600** | **Domestic DIY** | **~₹6,000–9,000 (mixed confidence)** | — |

## What's solid vs. what needs your own follow-up

**Well-verified — live links, consistent multi-source prices:**
- Gold cup electrodes (item 2)
- Ten20 paste (item 5)
- NuPrep gel (item 6)
- Pogo pins (item 7) — pricing solid; plating-safety concern documented from independent electronics-industry sources
- Fab.to.Lab dry spike electrode (item 1 fallback)

**Directionally right but not individually link-verified — re-search before ordering:**
- Ear clip electrode standalone pricing (item 3)
- Disposable ECG electrode supplier links (item 4) — price range credible, specific listing links lost
- Silver conductive paint (item 8)
- Wire, Dupont kits, 2×13 header (items 9–11) — commodity electronics, low risk, but SKUs churn too fast for a stable link to be worth much

**Confirmed absent, not just unverified:**
- True multi-prong dry comb electrode manufactured in India (item 1, main product)
- Extended 10-10 textile cap manufactured in India (item 12)

If you want the "directionally right" rows fully link-verified too, I can run a second, narrower research pass specifically on the ECG electrodes, wire, Dupont kits, and headers so the whole document is link-backed rather than mixed-confidence.

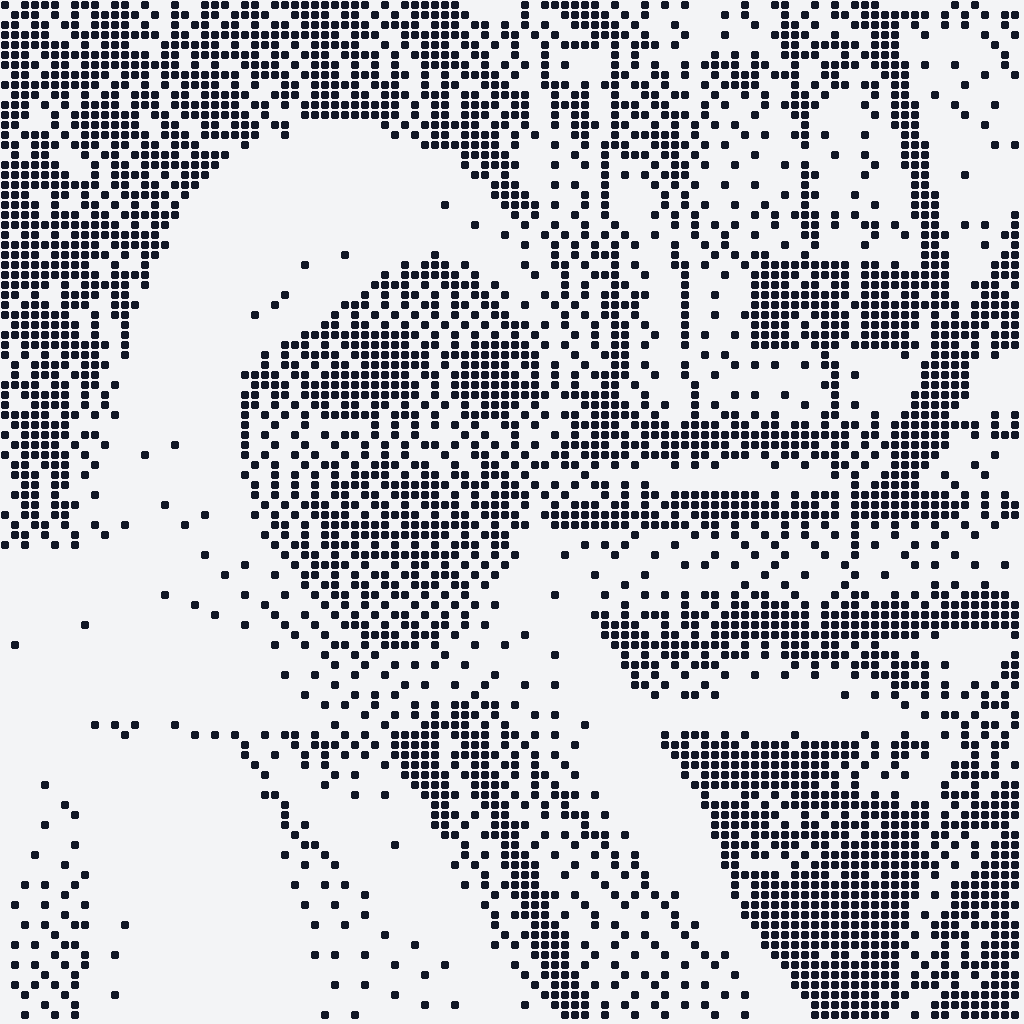
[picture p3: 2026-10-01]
hardware/reference/dot-art-1784129771636.png

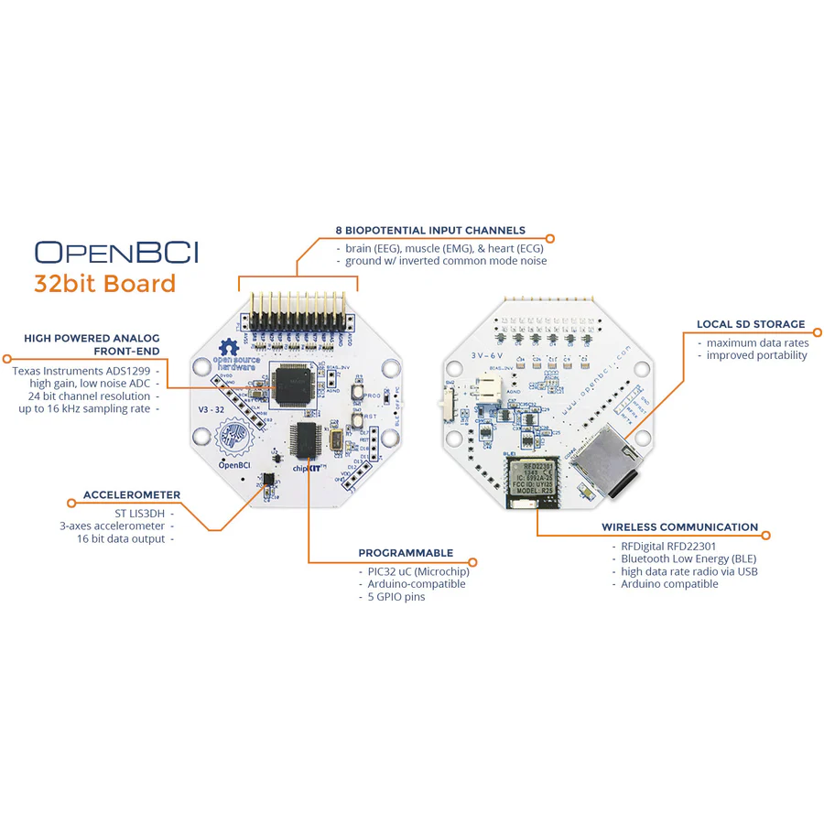
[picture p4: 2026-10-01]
hardware/reference/8_channel_1.webp

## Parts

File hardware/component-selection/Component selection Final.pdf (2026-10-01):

PCB | Bill of Materials | Component Placements | Quote & Order

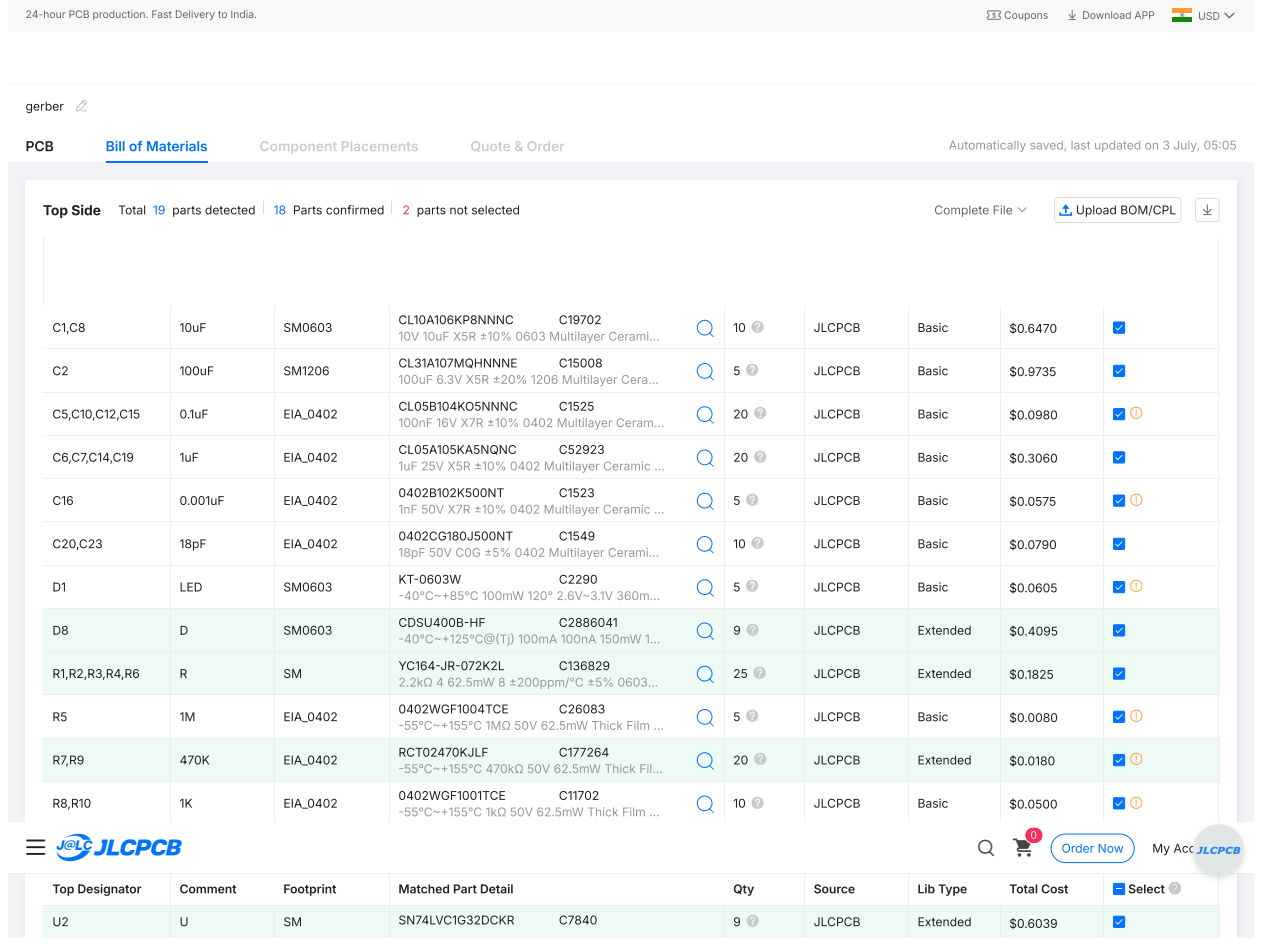
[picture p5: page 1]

Automatically saved, last updated on 3 July, 05:05

C2 | 100uF | SM1206 | CL31A107MQHNNNE C15008 100uF 6.3V X5R ±20% 1206 Multilayer Cera… | 5 | JLCPCB | Basic | $0.9735

C5,C10,C12,C15 | 0.1uF | EIA_0402 | CL05B104KO5NNNC C1525 100nF 16V X7R ±10% 0402 Multilayer Ceram… | 20 | JLCPCB | Basic | $0.0980

C6,C7,C14,C19 | 1uF | EIA_0402 | CL05A105KA5NQNC C52923 1uF 25V X5R ±10% 0402 Multilayer Ceramic … | 20 | JLCPCB | Basic | $0.3060

C16 | 0.001uF | EIA_0402 | 0402B102K500NT C1523 1nF 50V X7R ±10% 0402 Multilayer Ceramic … | 5 | JLCPCB | Basic | $0.0575

C20,C23 | 18pF | EIA_0402 | 0402CG180J500NT C1549 18pF 50V C0G ±5% 0402 Multilayer Cerami… | 10 | JLCPCB | Basic | $0.0790

D1 | LED | SM0603 | KT-0603W C2290 -40℃~+85℃ 100mW 120° 2.6V~3.1V 360m… | 5 | JLCPCB | Basic | $0.0605

D8 | D | SM0603 | CDSU400B-HF C2886041 -40℃~+125℃@(Tj) 100mA 100nA 150mW 1… | 9 | JLCPCB | Extended | $0.4095

R1,R2,R3,R4,R6 | R | SM | YC164-JR-072K2L C136829 2.2kΩ 4 62.5mW 8 ±200ppm/℃ ±5% 0603… | 25 | JLCPCB | Extended | $0.1825

R5 | 1M | EIA_0402 | 0402WGF1004TCE C26083 -55℃~+155℃ 1MΩ 50V 62.5mW Thick Film … | 5 | JLCPCB | Basic | $0.0080

R7,R9 | 470K | EIA_0402 | RCT02470KJLF C177264 -55℃~+155℃ 470kΩ 50V 62.5mW Thick Fil… | 20 | JLCPCB | Extended | $0.0180

R8,R10 | 1K | EIA_0402 | 0402WGF1001TCE C11702 -55℃~+155℃ 1kΩ 50V 62.5mW Thick Film … | 10 | JLCPCB | Basic | $0.0500

SW1,SW3 (https://jlcpcb.com/) Uploaded (https://jlcpcb.com/) BOM Data | S | SM | PTS810SJK250SMTRLFS C221896 -40℃~+85℃ 16V 2.5mm 2.6N 3.2mm 4.2m… | 10 Review Matched Parts | JLCPCB | Extended | $4.661 (https://cart.jlcpcb.com/shopcart/cart)0 (https://cart.jlcpcb.com/quote?spm=Jlcpcb.Homepage.1006&spm=Jlcpcb.Homepage.1006)

Top Designator U1 | U Comment | LGA Footprint | LIS3DHTR C15134 Matched Part Detail -40℃~+85℃ 1.71V~3.6V 16bit 500nA Accel… | Qty 5 | JLCPCB Source | Extended Lib Type | Total Cost $7.7940 | Select

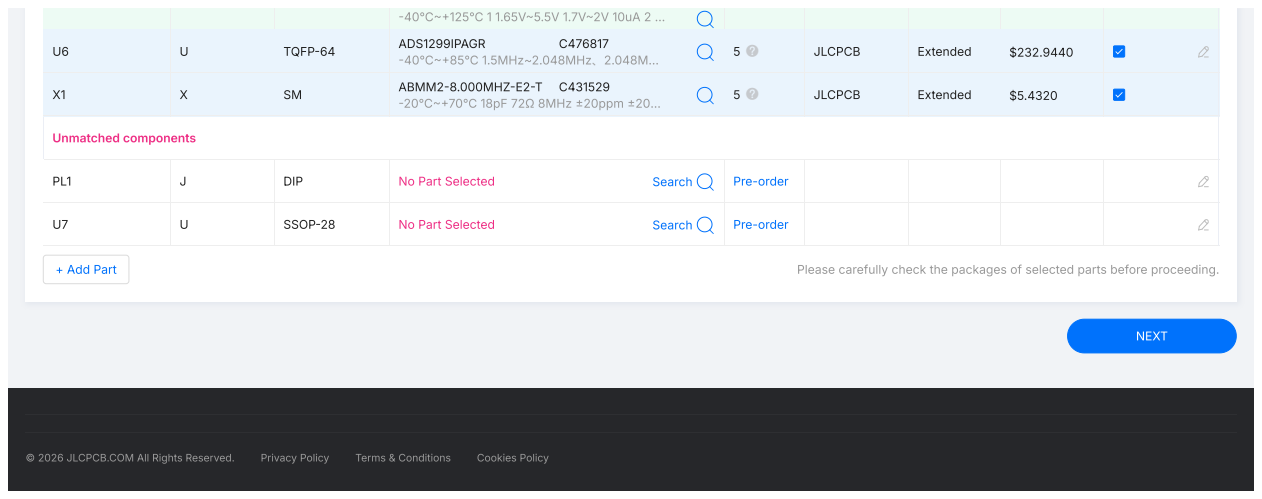
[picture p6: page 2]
© 2026 JLCPCB.COM All Rights Reserved.; Privacy Policy; Terms & Conditions; Cookies Policy; + Add Part; Please carefully check the packages of selected parts before proceeding.; Unmatched components; NEXT

U6 | U | TQFP-64 | ADS1299IPAGR C476817 -40℃~+85℃ 1.5MHz~2.048MHz、2.048M… | 5 | JLCPCB | Extended | $232.9440

X1 | X | SM | ABMM2-8.000MHZ-E2-T C431529 -20℃~+70℃ 18pF 72Ω 8MHz ±20ppm ±20… | 5 | JLCPCB | Extended | $5.4320

PL1 | J | DIP | No Part Selected Search | Pre-order

U7 | U | SSOP-28 | No Part Selected Search | Pre-order

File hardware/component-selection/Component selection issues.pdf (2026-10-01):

PCB | Bill of Materials | Component Placements | Quote & Order

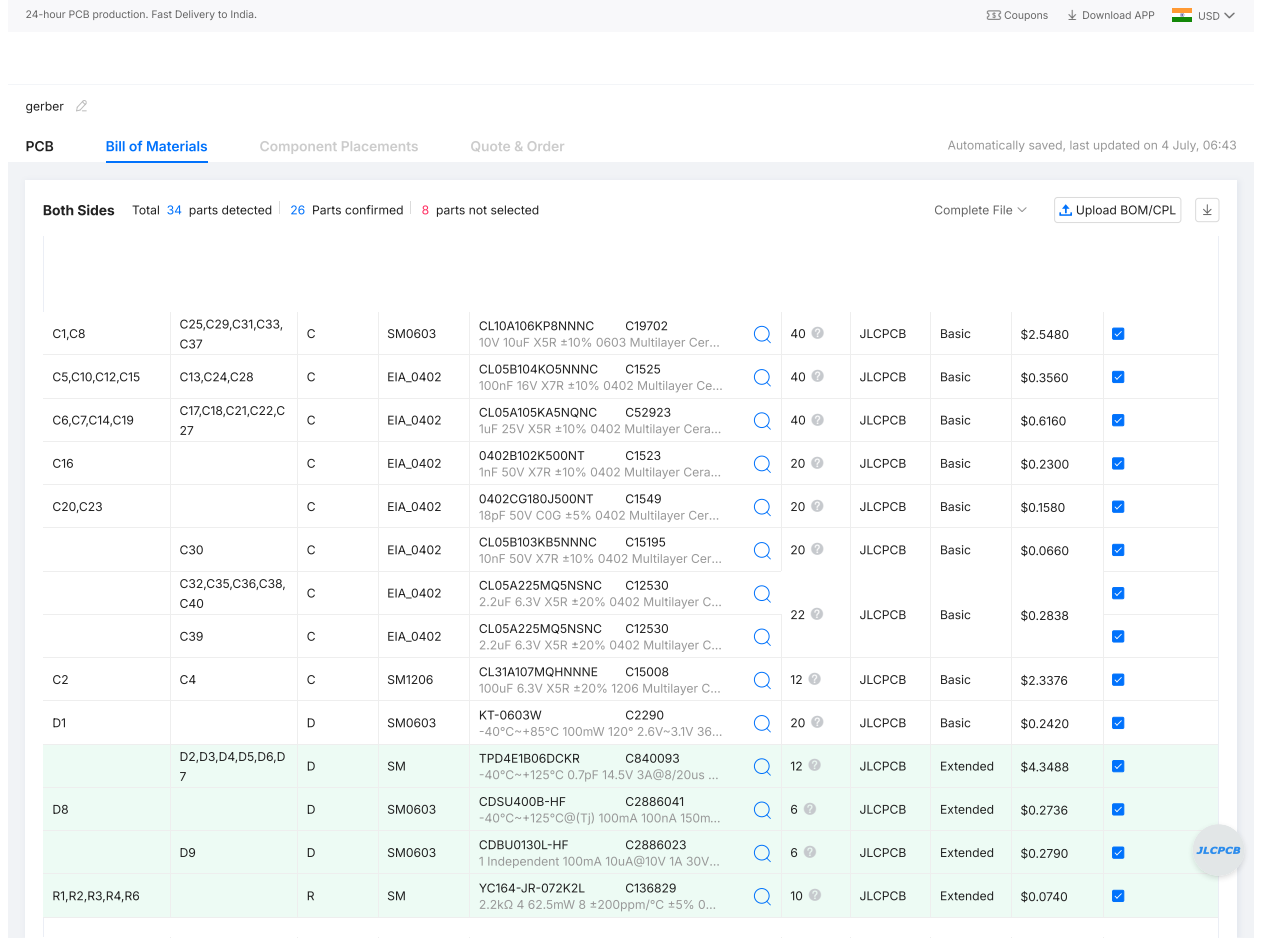
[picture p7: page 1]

Automatically saved, last updated on 4 July, 06:43

C5,C10,C12,C15 | C13,C24,C28 | C | EIA_0402 | CL05B104KO5NNNC C1525 100nF 16V X7R ±10% 0402 Multilayer Ce… | 40 | JLCPCB | Basic | $0.3560

C6,C7,C14,C19 | C17,C18,C21,C22,C 27 | C | EIA_0402 | CL05A105KA5NQNC C52923 1uF 25V X5R ±10% 0402 Multilayer Cera… | 40 | JLCPCB | Basic | $0.6160

C16 | | C | EIA_0402 | 0402B102K500NT C1523 1nF 50V X7R ±10% 0402 Multilayer Cera… | 20 | JLCPCB | Basic | $0.2300

C20,C23 | | C | EIA_0402 | 0402CG180J500NT C1549 18pF 50V C0G ±5% 0402 Multilayer Cer… | 20 | JLCPCB | Basic | $0.1580

C30 | C | EIA_0402 | CL05B103KB5NNNC C15195 10nF 50V X7R ±10% 0402 Multilayer Cer… | 20 | JLCPCB | Basic | $0.0660

C32,C35,C36,C38, C40 | C | EIA_0402 | CL05A225MQ5NSNC C12530 2.2uF 6.3V X5R ±20% 0402 Multilayer C… | 22 | JLCPCB | Basic | $0.2838

C39 | C | EIA_0402 | CL05A225MQ5NSNC C12530 2.2uF 6.3V X5R ±20% 0402 Multilayer C…

C2 | C4 | C | SM1206 | CL31A107MQHNNNE C15008 100uF 6.3V X5R ±20% 1206 Multilayer C… | 12 | JLCPCB | Basic | $2.3376

D1 | | D | SM0603 | KT-0603W C2290 -40℃~+85℃ 100mW 120° 2.6V~3.1V 36… | 20 | JLCPCB | Basic | $0.2420

D2,D3,D4,D5,D6,D 7 | D | SM | TPD4E1B06DCKR C840093 -40℃~+125℃ 0.7pF 14.5V 3A@8/20us … | 12 | JLCPCB | Extended | $4.3488

D8 | | D | SM0603 | CDSU400B-HF C2886041 -40℃~+125℃@(Tj) 100mA 100nA 150m… | 6 | JLCPCB | Extended | $0.2736

D9 | D | SM0603 | CDBU0130L-HF C2886023 1 Independent 100mA 10uA@10V 1A 30V… | 6 | JLCPCB | Extended | $0.2790

R1,R2,R3,R4,R6 | | R | SM | YC164-JR-072K2L C136829 2.2kΩ 4 62.5mW 8 ±200ppm/℃ ±5% 0… | 10 | JLCPCB | Extended | $0.0740

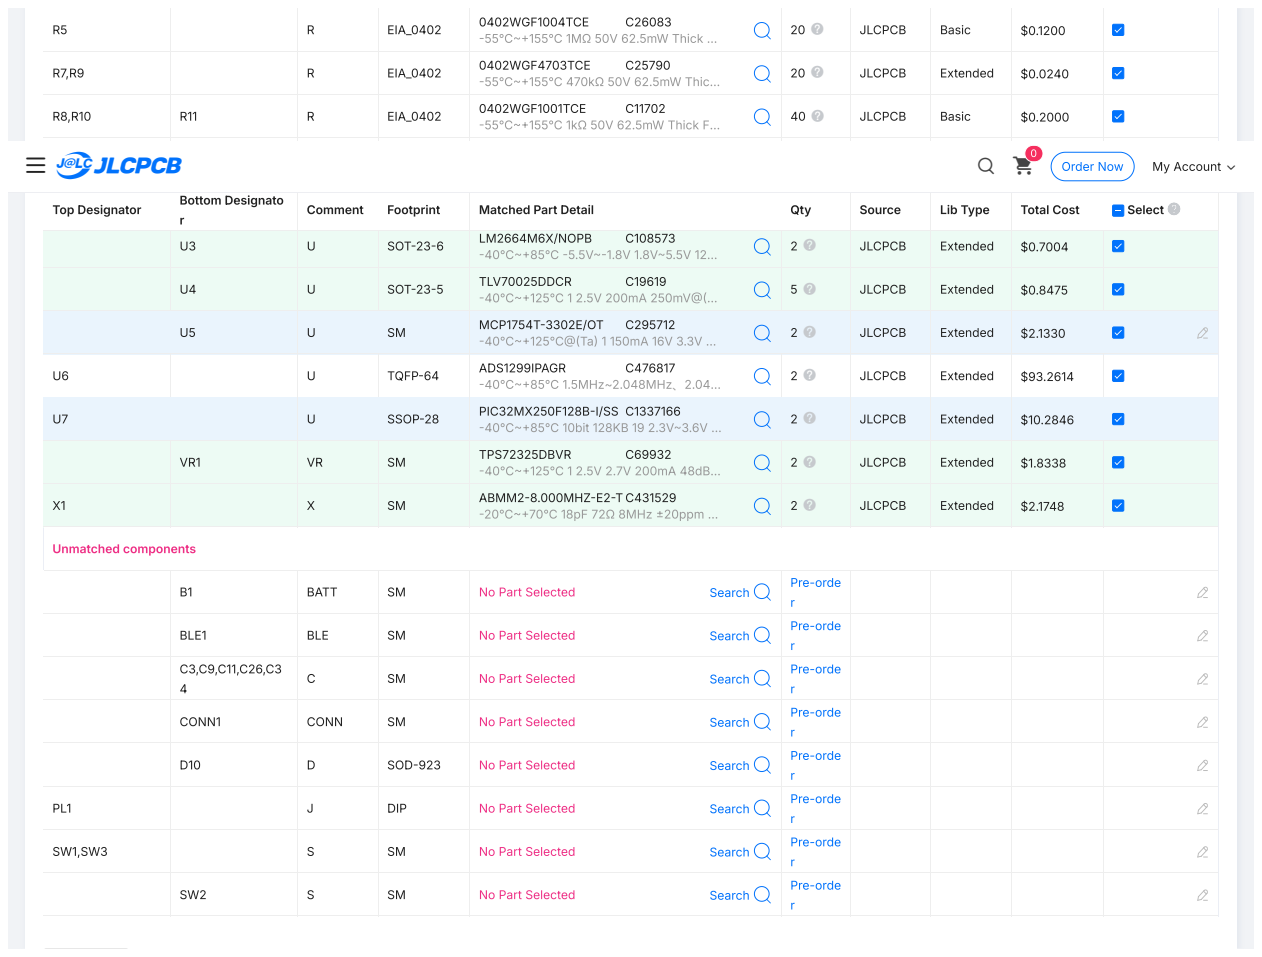
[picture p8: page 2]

R7,R9 | | R | EIA_0402 | 0402WGF4703TCE C25790 -55℃~+155℃ 470kΩ 50V 62.5mW Thic… | 20 | JLCPCB | Extended | $0.0240

R8,R10 | R11 | R | EIA_0402 | 0402WGF1001TCE C11702 -55℃~+155℃ 1kΩ 50V 62.5mW Thick F… | 40 | JLCPCB | Basic | $0.2000

U1 (https://jlcpcb.com/) | Uploaded BOM Data | U | LGA | -40℃~+85℃ 1.71V~3.6V 16bit 500nA A… Review Matched Parts | 2 | JLCPCB | Extended | $3.18 (https://cart.jlcpcb.com/shopcart/cart)48 (https://cart.jlcpcb.com/quote?spm=Jlcpcb.Homepage.1006&spm=Jlcpcb.Homepage.1006)

LIS3DHTR C15134 | | | | 0

U3 | U | SOT-23-6 | LM2664M6X/NOPB C108573 -40℃~+85℃ -5.5V~-1.8V 1.8V~5.5V 12… | 2 | JLCPCB | Extended | $0.7004

U4 | U | SOT-23-5 | TLV70025DDCR C19619 -40℃~+125℃ 1 2.5V 200mA 250mV@(… | 5 | JLCPCB | Extended | $0.8475

U5 | U | SM | MCP1754T-3302E/OT C295712 -40℃~+125℃@(Ta) 1 150mA 16V 3.3V … | 2 | JLCPCB | Extended | $2.1330

U6 | | U | TQFP-64 | ADS1299IPAGR C476817 -40℃~+85℃ 1.5MHz~2.048MHz、2.04… | 2 | JLCPCB | Extended | $93.2614

U7 | | U | SSOP-28 | PIC32MX250F128B-I/SS C1337166 -40℃~+85℃ 10bit 128KB 19 2.3V~3.6V … | 2 | JLCPCB | Extended | $10.2846

VR1 | VR | SM | TPS72325DBVR C69932 -40℃~+125℃ 1 2.5V 2.7V 200mA 48dB… | 2 | JLCPCB | Extended | $1.8338

X1 | | X | SM | ABMM2-8.000MHZ-E2-T C431529 -20℃~+70℃ 18pF 72Ω 8MHz ±20ppm … | 2 | JLCPCB | Extended | $2.1748

B1 | BATT | SM | No Part Selected Search | Pre-orde r

BLE1 | BLE | SM | No Part Selected Search | Pre-orde r

C3,C9,C11,C26,C3 4 | C | SM | No Part Selected Search | Pre-orde r

CONN1 | CONN | SM | No Part Selected Search | Pre-orde r

D10 | D | SOD-923 | No Part Selected Search | Pre-orde r

PL1 | | J | DIP | No Part Selected Search | Pre-orde r

SW1,SW3 | | S | SM | No Part Selected Search | Pre-orde r

SW2 | S | SM | No Part Selected Search | Pre-orde r

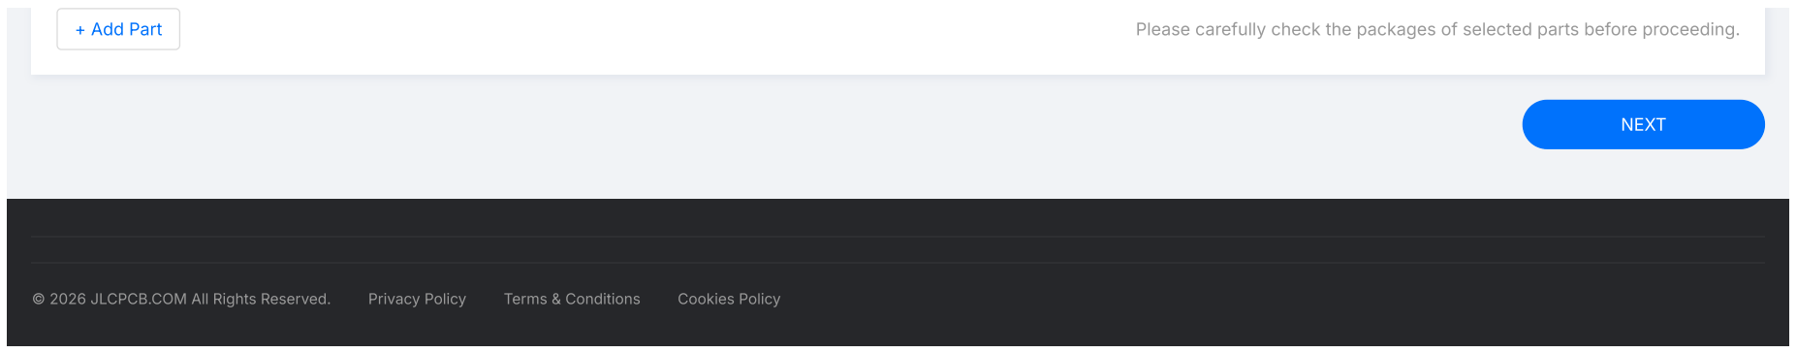
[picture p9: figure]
NEXT

© 2026 JLCPCB.COM All Rights Reserved. | Privacy Policy (https://jlcpcb.com/help/article/Privacy-Policy) | Terms & Conditions (https://jlcpcb.com/help/article/Terms-%26-Conditions) | Cookies Policy (https://jlcpcb.com/help/article/JLCPCB-Cookie-Notice)
+ Add Part | Please carefully check the packages of selected parts before proceeding.

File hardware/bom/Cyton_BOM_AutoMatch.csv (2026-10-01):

Item | Designator | Qty | Comment | Value | Footprint | Manufacturer | Manufacturer Part | Description | LCSC Part #
1 | C2,C4 | 2 | C | 100uF | SM 1206 | Yageo | CC1206MKX5R5BB107 | MLCC | C15008
2 | C1,C8,C25,C29,C31,C33,C37 | 7 | C | 10uF | SM0603 | Murata | GRM188C80G106KE47D | MLCC | C19702
3 | C32,C35,C36,C38,C40 | 5 | C | 2.2uF | EIA_0402 | Murata | GRM155C80J225ME95D | MLCC | C12530
4 | C39 | 1 | C | 2.2uF | EIA_0402 | Murata | GRM155R61C225KE44D | MLCC | C170151
5 | C6,C7,C14,C17,C18,C19,C21,C22,C27 | 9 | C | 1uF | EIA_0402 | Yageo | CC0402KRX7R5BB105 | MLCC | C52923
6 | C5,C10,C12,C13,C15,C24,C28 | 7 | C | 0.1uF | EIA_0402 | Yageo | CC0402KRX7R7BB104 | MLCC | C1525
7 | C30 | 1 | C | 0.01uF | EIA_0402 | Yageo | CC0402KRX7R7BB103 | MLCC | C15195
8 | C16 | 1 | C | 0.001uF | EIA_0402 | Yageo | CC0402KRX7R7BB102 | MLCC | C1523
9 | C20,C23 | 2 | C | 18pF | EIA_0402 | Yageo | CC0402JRNPO9BN180 | MLCC | C1549
10 | R1,R2,R3,R4,R6 | 5 | R | 2.2K | SM | Yageo | YC164-JR-072K2L | 4 R-ARRAY | C136829
11 | C3,C9,C11,C26,C34 | 5 | C | 0.001uF | SM | Yageo | CA0508KRX7R9BB102 | 4 CAP ARRAY | C576623
12 | U1 | 1 | U |  | LGA | ST | LIS3DHTR | ST ACCELEROMETER | C15134
13 | U2 | 1 | U |  | SM | TI | SN74LVC1G32DCKR | OR_GATE | C7840
14 | U3 | 1 | U |  | SOT-23-6 | TI | LM2664M6/NOPB | V INVERTER | C108573
15 | U4 | 1 | U |  | SOT-23-5 | TI | TLV70025QDDCRQ1 | +2.5V LDO REG | C19619
16 | U5 | 1 | U |  | SM | Microchip | MCP1754T-3302E/OT | 3V3 LDO REG | C295712
17 | U6 | 1 | U |  | TQFP-64 | TI | ADS1299IPAG | ADS1299 | C476817
18 | U7 | 1 | U |  | SSOP-28 | Microchip | PIC32MX250F128B-I/SS | PIC32 MICROCONTROLLER | C1337166
19 | VR1 | 1 | VR |  | SM | TI | TPS72325DBVR | -2.5 LDO REG | C69932
20 | BLE1 | 1 | BLE |  | SM | RF DIGITAL | RFD22301 | BTLE Module
21 | D1 | 1 | D | LED | SM 0603 | Lite-On | LTST-C193TBKT-5A | BLUE LED | C2290
22 | D8 | 2 | D |  | SM 0603 | Generic | 1N4148WT | DIODE | C232841
23 | D9 | 1 | D |  | SM 0603 | Generic | BAT54X | DIODE | C19627026
24 | D2,D3,D4,D5,D6,D7 | 6 | D |  | SM | TI | TPD4E1B06DCKR | TI QUAD TVS | C840093
25 | D10 | 1 | D | 3V | SOD-923 | Diodes Inc | DZ9F3V0S92-7 | 3V Zener Diode | C5244901
26 | R8,R10,R11 | 3 | R | 1K | EIA_0402 | Yageo | RT0402FRE071KL | Resistor | C11702
27 | R5 | 1 | R | 1M | EIA_0402 | Yageo | RC0402JR-071ML | Resistor | C26083
28 | R7,R9 | 2 | R | 470K | EIA_0402 | Yageo | RC0402JR-07470KL | Resistor | C25790
29 | X1 | 1 | X | 8MHz | SM | ABRACON | ABMM2-8.000MHZ-E2-T | 8MHz XTAL | C431529
30 | B1 | 1 | BATT |  | SM | JST Sales | S2B-PH-SM4-TB(LF)(SN) | CONN HEADER PH SIDE 2POS 2MM SMD | C295747
31 | SW2 | 1 | S |  | SM | COPAL | CUS-13TB | SP3T SLIDE SWITCH
32 | SW1,SW3 | 2 | S |  | SM | C&K | PTS810 SJK 250 SMTR LFS | TACT SWITCH | C2689510
33 | CONN1 | 1 | CONN |  | SM | SUNTECH | ST-TF-003A | microSD card slot | C91145
34 | PL1 | 1 | J |  | DIP | Wurth | 61302221021 | Dual 11 x 2 0.1" pitch MALE header row Right Angle

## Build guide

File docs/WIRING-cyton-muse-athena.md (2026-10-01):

# Wiring — Cyton ↔ Muse Athena Comparison Montage

**Purpose:** validate the self-fabricated Cyton against a commercial headset (Muse) using
frontal/temporal positions, with 3M Ag/AgCl ECG gel patches. No hair, no dry-electrode
problems, no custom mount required.

This is a **hardware validation test**, not a motor-imagery test. For MI see
`WIRING-motor-imagery.md`.

---

## Why this test

| | |
|---|---|
| **No hair** | ECG patches stick straight to skin. Removes the entire hair-penetration problem. |
| **Better electrodes than the bolts** | 3M patches are Ag/AgCl with wet gel — non-polarizable, low drift, low impedance. Materially better than SS 304. |
| **All electrodes matched** | Every contact is the same 3M Ag/AgCl. No dissimilar-metal DC offset. |
| **Ground truth available** | You own a Muse. Same positions → direct comparison against a commercial device. |
| **Strong, obvious signals** | Frontal sites give the largest blink and EOG artifacts on the head. Easy to confirm life. |

---

## PL1 pinout reference

PL1 is `26WDP` — **26 pins, 13 rows × 2**. Odd pins are the left column (`PL1a`),
even pins the right (`PL1b`).

`26WDP` = **26-Way Dual Pin** — 13 rows, two pins side by side per row. Odd numbers
run down one column, even down the other; pins 1 and 2 are adjacent.

```
        ODD COLUMN (PL1a)          EVEN COLUMN (PL1b)
        pin   signal               pin   signal
        ───   ──────               ───   ──────
  row A   1   AVDD                   2   AVDD
  row B   3   AGND                   4   AGND
  row C   5   BIAS  ★                6   BIAS
  row D   7   8N    ← ch8            8   8P
  row E   9   7N    ← ch7           10   7P
  row F  11   6N    ← ch6           12   6P
  row G  13   5N    ← ch5           14   5P
  row H  15   4N    ← ch4           16   4P
  row I  17   3N    ← ch3           18   3P
  row J  19   2N    ← ch2  ★        20   2P
  row K  21   1N    ← ch1  ★        22   1P
  row L  23   SRB2  ★               24   SRB1
  row M  25   AVSS                  26   AVSS

  ★ = pins used in this test
```

### ⚠️ Electrodes go to the **N** pins, not the P pins

The default channel settings close an internal switch between each channel's
**P input and SRB2** — confirmed in `OpenBCI_32bit_Library.cpp`:

```cpp
defaultChannelSettings[SRB2_SET] = YES;   // connect this P side to SRB2
```

So the P inputs are already taken by the shared reference. **Your scalp electrode
connects to the channel's N pin.**

Convenient consequence: for standard referential recording **everything you need is
in the odd column** — N pins, SRB2, and BIAS are all odd-numbered.

⚠️ **Channel order is reversed** — channel 8 is near the top, channel 1 near the bottom.

---

## Muse electrode positions

The classic Muse layout is **TP9, AF7, AF8, TP10**, referenced to **Fpz**.

> ⚠️ **Verify this against the Athena's own documentation before relying on it for a
> like-for-like comparison.** The Athena is a newer model and may differ from the
> Muse 2 / Muse S layout. The positions below are the standard Muse montage.

| Muse site | Where it sits |
|---|---|
| **Fpz** | Centre of forehead, above the bridge of the nose (reference) |
| **AF7** | Left forehead, above the outer third of the left eyebrow |
| **AF8** | Mirror image on the right |
| **TP9** | Behind the left ear, on the mastoid bone |
| **TP10** | Behind the right ear, on the mastoid bone |

---

## Option A — Minimal 2-channel test (start here)

Four patches. Fastest path to "is my board reading a real brain".

| Electrode | Position | → PL1 pin | Cyton channel |
|---|---|---:|---|
| Patch 1 | **AF7** (left forehead) | **21** | ch1 (**1N**) |
| Patch 2 | **AF8** (right forehead) | **19** | ch2 (**2N**) |
| Patch 3 | **Fpz** (centre forehead) | **23** | SRB2 — reference |
| Patch 4 | **Mastoid or earlobe** | **5** | BIAS |

## Option B — Full 4-channel Muse-equivalent

Six patches. Gives you all four Muse sites for a proper comparison.

| Electrode | Position | → PL1 pin | Cyton channel |
|---|---|---:|---|
| Patch 1 | **AF7** | **21** | ch1 (**1N**) |
| Patch 2 | **AF8** | **19** | ch2 (**2N**) |
| Patch 3 | **TP9** (behind left ear) | **17** | ch3 (**3N**) |
| Patch 4 | **TP10** (behind right ear) | **15** | ch4 (**4N**) |
| Patch 5 | **Fpz** | **23** | SRB2 — reference |
| Patch 6 | **Earlobe or neck** | **5** | BIAS |

> **BIAS is not optional.** It is a *driven* electrode — the amplifier pushes current
> into it to hold your body's common-mode voltage inside the input range. Without it,
> 50 Hz mains swamps everything and channels may rail.
>
> Unlike the reference, **BIAS material does not need to match** — it is never
> subtracted from the signal.

---

## Connecting to the board

PL1 is unpopulated, so:

1. **Solder single male header pins** into only the holes you need (snap them off a
   breakaway strip). That's 4 pins for Option A, 6 for Option B.
2. Your **alligator-clip-to-Dupont-female** leads then plug straight onto those pins.
3. Clip the alligator jaw onto the **snap stud** of each ECG patch — it grips the metal
   post fine, no snap adapter needed.

Keep the leads loose. ECG patch adhesive is not strong enough to survive a taut wire.

---

## Skin prep

Forehead skin is oily and this matters more than people expect.

1. Wipe each site with an **alcohol swab**, let it dry fully.
2. Press the patch down firmly for a few seconds; make sure the gel contacts skin
   across the whole disc, not just the rim.
3. Leave 2–3 minutes before recording — freshly applied gel electrodes drift while the
   gel settles into the skin.

---

## Test protocol

Run in order. Each step proves more than the last.

| # | Action | Expected |
|---:|---|---|
| 1 | Send `[` (2× square wave) | Clean square wave. Confirms the **board** is fine independent of electrodes. |
| 2 | Send `d` then `b` | Back to normal inputs, streaming |
| 3 | **Blink hard ×5** | Huge deflections (hundreds of µV) on AF7/AF8. **This is your proof of life.** |
| 4 | **Look hard left, then right** | EOG step artifacts, opposite polarity on AF7 vs AF8 |
| 5 | **Clench jaw 2 s** | Dense high-frequency EMG burst |
| 6 | **Eyes closed 20 s / open 20 s ×3** | Alpha (8–12 Hz) rises with eyes closed. Weaker frontally than occipitally but usually visible. |

If step 3 works, you have real biopotentials and the whole chain is proven.

---

## Comparing against the Muse

You can't easily sync timestamps between the two devices, so compare **event-locked
effects** rather than raw traces:

1. Run the **eyes-closed / eyes-open** block (step 6) on the Muse, note the alpha change
   its app reports.
2. Repeat the identical block on the Cyton.
3. Compare the **ratio** of alpha power (8–12 Hz) between eyes-closed and eyes-open on
   each device.

The absolute µV values will differ — different reference, different gain, different
electrode contact. **The eyes-closed/open alpha ratio is the comparable number**, and it
should be in the same ballpark on both if your board is working correctly.

Blink amplitude is a useful second check — it should be large and obvious on both.

---

## What to expect on screen

The live web UI plots **raw, unfiltered** data.

- **50 Hz mains will be prominent.** Your training pipeline bandpasses 4–40 Hz, which
  removes mains entirely, but the live plot has no filter yet.
- **Slow drift** in the first minute or two as gel settles.
- **Blinks will be unmistakable** — they are far larger than anything else here.

If a channel sits at `±187500 µV` it is **railed** — the patch has lifted, or BIAS is
not connected.

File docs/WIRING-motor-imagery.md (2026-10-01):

# Wiring — Motor Imagery Montage

**Purpose:** the production montage for left-vs-right hand motor imagery, matching the
channels the models were trained on.

For the frontal hardware-validation test with ECG patches, see
`WIRING-cyton-muse-athena.md`.

---

## The target montage

Fixed by the training pipeline — `Neuro-Rehab-git/src/run_ablation.sh`:

```bash
# Simulates testing 8-channel consumer EEG hardware (e.g. ADS1299)
CHANNELS="C3 Cz C4 FC3 FC4 CP3 CP4"
```

Same seven in `cache_foundation.py` and `cache_openbmi.py`. A 5-channel subset
(`C3, Cz, C4, CP3, CP4`) is used by `train_physionet_5ch.py` → `Models/neurorehab_bci_5ch.pth`.

**7 scalp + 1 reference + 1 bias = 9 electrodes.** Cyton has 8 inputs, so 7 used, 1 spare.

```
        FC3    ·    FC4
         C3   Cz    C4          3x3 grid centred on Cz
        CP3    ·    CP4          ~12 cm ear-to-ear, ~8 cm front-to-back
```

---

## PL1 pinout reference

PL1 is `26WDP` — **26 pins, 13 rows × 2**. Odd = left column (`PL1a`), even = right (`PL1b`).

`26WDP` = **26-Way Dual Pin** — 13 rows, two pins side by side per row. Odd numbers
run down one column, even down the other; pins 1 and 2 are adjacent.

```
        ODD COLUMN (PL1a)          EVEN COLUMN (PL1b)
        pin   signal               pin   signal
        ───   ──────               ───   ──────
  row A   1   AVDD                   2   AVDD
  row B   3   AGND                   4   AGND
  row C   5   BIAS  ★                6   BIAS
  row D   7   8N    ← ch8            8   8P
  row E   9   7N    ← ch7  ★        10   7P
  row F  11   6N    ← ch6  ★        12   6P
  row G  13   5N    ← ch5  ★        14   5P
  row H  15   4N    ← ch4  ★        16   4P
  row I  17   3N    ← ch3  ★        18   3P
  row J  19   2N    ← ch2  ★        20   2P
  row K  21   1N    ← ch1  ★        22   1P
  row L  23   SRB2  ★               24   SRB1
  row M  25   AVSS                  26   AVSS

  ★ = pins used by the 7-channel montage
```

### ⚠️ Electrodes go to the **N** pins, not the P pins

The default channel settings close an internal switch between each channel's
**P input and SRB2** — confirmed in `OpenBCI_32bit_Library.cpp`:

```cpp
defaultChannelSettings[SRB2_SET] = YES;   // connect this P side to SRB2
```

The P inputs are already taken by the shared reference, so **scalp electrodes connect
to the channel's N pin.**

Convenient consequence: for standard referential recording **everything you need is in
the odd column** — N pins, SRB2, and BIAS are all odd-numbered.

⚠️ **Channel order is reversed** — channel 8 near the top, channel 1 near the bottom.

### Polarity note

Because the reference sits on P and the electrode on N, the amplifier computes
`P − N` = `reference − electrode`, i.e. the signal is **inverted** relative to the usual
`electrode − reference` convention.

For band-power features (mu/beta ERD) this makes no difference — power is
sign-independent. For a model that consumes **raw time series** (EEGNet does), a global
sign flip is a real domain shift versus the training data. Check it empirically with the
blink test and negate in the client if needed.

---

## Option A — Full 7-channel (production montage)

| Electrode | → PL1 pin | Cyton channel | Used by 5ch model? |
|---|---:|---|---|
| **C3** | **21** | ch1 (**1N**) | ✅ |
| **Cz** | **19** | ch2 (**2N**) | ✅ |
| **C4** | **17** | ch3 (**3N**) | ✅ |
| **FC3** | **15** | ch4 (**4N**) | — |
| **FC4** | **13** | ch5 (**5N**) | — |
| **CP3** | **11** | ch6 (**6N**) | ✅ |
| **CP4** | **9** | ch7 (**7N**) | ✅ |
| **Reference** (mastoid or earlobe) | **23** | SRB2 | — |
| **BIAS** (other mastoid/earlobe) | **5** | BIAS | — |

Record all 7; feed whichever 5 the current model wants. Costs two extra electrodes and
gives you data to retrain an 8-channel model later without re-gelling anyone.

---

## Option B — 3-electrode minimum (Cz as reference)

For a first motor-imagery test with a case that only has C3/Cz/C4 provisions.

| Electrode | → PL1 pin | Cyton channel |
|---|---:|---|
| **C3** | **21** | ch1 (**1N**) |
| **C4** | **19** | ch2 (**2N**) |
| **Cz** | **23** | SRB2 — **reference** |
| **BIAS** (forehead / mastoid / earlobe) | **5** | BIAS |

### Why Cz-as-reference is legitimate here

```
ch1 = C3 − Cz
ch2 = C4 − Cz
ch1 − ch2 = C3 − C4        ← Cz cancels completely
```

Left-vs-right MI is classified on the **lateralisation** between C3 and C4. A common
reference subtracted from both leaves that difference untouched, so the discriminative
information survives intact.

**Cost:** Cz sits on the motor strip and carries its own mu rhythm, so absolute
amplitudes shrink. The left/right asymmetry — the thing that matters — does not.

**This gives 2 channels**, so it will not run the 5ch or 7ch models. It is a hardware
and physiology test, not a model test.

---

## Electrode material rules

| Electrode | Matching required? | Why |
|---|---|---|
| **Signal** (C3, C4, …) | ✅ all same material | — |
| **Reference (SRB2)** | ✅ **must match the signal electrodes** | It is subtracted from every channel, so its half-cell potential appears as a DC offset on all of them |
| **BIAS** | ❌ anything conductive | Driven output, never subtracted from the signal |

> Mixing metals between signal and reference can produce a DC offset large enough to
> exceed the ADS1299's **±187.5 mV** input range (gain 24) and rail every channel.
>
> Once digitised in range, the pipeline's **4 Hz high-pass**
> (`raw.filter(4.0, 40.0)`) removes offset and drift entirely — so matched metals matter
> for *staying in range*, not for the filtered signal.

---

## Finding the positions

Use the standard 10-20 measurement rather than eyeballing — placement repeatability is
what makes per-session calibration work.

1. **Nasion → inion** over the top of the head. **Cz is at 50%.**
2. **Left preauricular → right preauricular** through Cz. Confirm Cz at 50% of this too.
3. **C3** is 20% of the ear-to-ear distance left of Cz; **C4** is 20% right.
4. **FC3 / FC4** sit halfway between C3/C4 and F3/F4 — roughly 2 cm forward of C3/C4.
5. **CP3 / CP4** sit halfway between C3/C4 and P3/P4 — roughly 2 cm behind.

FC and CP are **10-10 positions**, not part of the 19-site 10-20 set. A cap marked only
for 10-20 will not have them.

---

## Test protocol

| # | Action | Expected |
|---:|---|---|
| 1 | Send `[` | Clean square wave — proves the board independent of electrodes |
| 2 | Send `d`, then `b` | Normal inputs, streaming |
| 3 | **Blink ×5** | Visible but *smaller* than frontal — these are central sites |
| 4 | **Clench jaw** | EMG burst |
| 5 | **Eyes closed / open, 20 s blocks** | Alpha/mu change in 8–13 Hz |
| 6 | **Squeeze RIGHT hand, 5 s on / 5 s off ×10** | **Mu suppression at C3** (contralateral) |
| 7 | **Squeeze LEFT hand, same pattern** | **Mu suppression at C4** |
| 8 | **Imagine the same squeezes** | Same effect, weaker |

**Steps 6–7 are the real milestone.** Contralateral mu ERD with actual movement is the
physiological basis of motor imagery — if it appears, imagery is within reach and
everything after is signal processing.

---

## What to expect on screen

The live web UI plots **raw, unfiltered** data.

- **50 Hz mains** will be prominent. The training pipeline bandpasses **4–40 Hz**, which
  removes mains entirely — the live view has no filter yet.
- **Mu is 8–13 Hz** and will be buried under mains in the raw view. A 4–40 Hz bandpass
  plus a 50 Hz notch on the live plot makes steps 5–8 visible.
- `±187500 µV` on a channel means **railed** — electrode lifted, or BIAS not connected.

---

## Open items

- [ ] Solder header pins / wires into PL1 (unpopulated). **Count the pads — it is 13×2,
      not the 11×2 the project README claims.**
- [ ] Confirm gold cup pricing is per *set*, not per *piece* (IndiaMART listings are
      ambiguous — see `electrode_research.md`)
- [ ] FRI TDE 210 combs from Fab.to.Lab (₹95 ea at 10+) + printed `FRI_electrode_mount.stl`
- [ ] Add 4–40 Hz bandpass + 50 Hz notch to the live view
- [ ] Add per-channel contact/impedance indicator to the UI

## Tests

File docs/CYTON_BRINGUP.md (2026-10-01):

# OpenBCI Cyton — Self-Fabricated Board Bring-Up

**Complete technical record: fabrication through live 8-channel wireless EEG streaming.**

| | |
|---|---|
| **Board** | OpenBCI Cyton V3 (32-bit), self-fabricated via JLCPCB |
| **MCU** | PIC32MX250F128B, SSOP-28, Rev B0 |
| **AFE** | ADS1299IPAG, TQFP-64, 8 channels @ 250 SPS |
| **Accelerometer** | LIS3DHTR, LGA-16 |
| **Firmware** | OpenBCI_32bit_Library v3.1.5, built with `board.beginDebug()` |
| **Radio** | RFD22301 **not populated** — replaced with a Seeed XIAO ESP32C3 WiFi bridge |
| **Status** | ✅ 8 channels streaming at 250 Hz over WiFi, ±1 µV noise floor. Real EEG recorded on 2 frontal channels — see §12.3 |
| **Date** | Bring-up August 2026. Reorganised into this repo 1 October 2026 |

---

## Table of Contents

1. [System Architecture](#1-system-architecture)
2. [Hardware Inventory](#2-hardware-inventory)
3. [Source Repositories](#3-source-repositories)
4. [Schematic Reference](#4-schematic-reference)
5. [Firmware Reference](#5-firmware-reference)
6. [Serial Protocol Reference](#6-serial-protocol-reference)
7. [Bring-Up Procedure](#7-bring-up-procedure)
8. [The WiFi Bridge](#8-the-wifi-bridge)
9. [Software Stack](#9-software-stack)
10. [Results and Measurements](#10-results-and-measurements)
11. [Troubleshooting Catalogue](#11-troubleshooting-catalogue)
12. [Known Issues and Open Items](#12-known-issues-and-open-items)
13. [Appendix A — Source Files](#appendix-a--source-files)

---

## Where everything lives

This document is part of a repo that holds the entire record. Every path below is
relative to the repo root, `C:\Users\abhij\Desktop\NeuroRehab\cyton-hardware\`.

| Folder | What is in it |
|---|---|
| `docs/` | This document, the two wiring guides, the electrode research and the electrode decision |
| `hardware/` | What was sent to JLCPCB: `gerbers/`, `bom/` (BOM + CPL), `quotes/`, `component-selection/`, and `reference/` (schematic, board photos, DesignSpark source) |
| `firmware/cyton/` | The exact sketch flashed to the board — the one with `board.beginDebug()` — and the hex the IDE built from it |
| `firmware/bridge/` | The XIAO ESP32C3 bridge sketch |
| `firmware/images/` | `CytonDebug-with-bootloader.hex`, the merged image actually running on the PIC32 |
| `firmware/tools/` | `merge-hex.ps1` and `listen-cyton.ps1` |
| `software/` | Flask server, CLI client, cue protocols, fake bridge, web UI, and `recordings/` |
| `logs/` | The first serial capture taken off the board |
| `vendor/`, `mechanical/` | Upstream clones and headset STLs — on disk, git-ignored, pinned in `VENDOR.md` |

---

## 1. System Architecture

```
┌──────────────┐   UART 115200   ┌──────────────┐   WiFi TCP    ┌──────────────┐
│ OpenBCI      │  D11 ────────►  │ XIAO         │  192.168.4.1  │ Laptop       │
│ Cyton        │  D12 ◄────────  │ ESP32C3      │  :3000        │ Flask + web  │
│ PIC32MX250   │  GND ────────   │ (SoftAP)     │◄─────────────►│ UI / Python  │
│ + ADS1299    │                 │              │               │              │
└──────────────┘                 └──────────────┘               └──────────────┘
      │                                                                 │
      │ ICSP (PICkit 3.5) — programming only                            │
      │ D11/D12 also feed a USB-TTL adapter as an independent monitor   │
      └─────────────────────────────────────────────────────────────────┘
```

**Data path:** ADS1299 → SPI → PIC32 → UART2 (Serial1, D11/D12) → XIAO ESP32C3 → WiFi TCP → Python → browser.

**Why Serial1 and not Serial0:** the PIC's primary UART (Serial0) terminates at the unpopulated RFD22301 footprint with no accessible breakout. The debug UART (Serial1) lands on the ICSP header pins, which are exposed on J3/J4. Firmware built with `beginDebug()` mirrors all output to both ports and accepts commands on both. See §4.4.

---

## 2. Hardware Inventory

### 2.1 Fabrication

Board fabricated and assembled by JLCPCB from the OpenBCI V3 Hardware Design Files.

| Setting | Value | Rationale |
|---|---|---|
| Layers | 4 | Power/ground shielding planes for sensitive analog inputs |
| Material | FR-4, 1.6 mm | Standard |
| Surface finish | **ENIG** | **Mandatory.** HASL leaves uneven solder domes that cause the LGA-16 accelerometer to tombstone and risk bridges on the 0.5 mm-pitch ADS1299 TQFP-64 |
| Assembly | Both sides | |
| Confirm parts placement | Yes | CPL zero-degree conventions differ from JLCPCB tape-and-reel; an SMT engineer corrects centroids/rotations |
| Depanel | Yes | CNC removal of tooling rails |
| HS code | 847330 ("Development Board") | Classifying as medical/EEG triggers Indian customs holds demanding CDSCO/FDA import licences |

### 2.2 Deliberately unpopulated

| Ref | Part | Reason | Consequence |
|---|---|---|---|
| **BLE1** | RFD22301 BTLE module | Obsolete, not stocked by JLCPCB | **No radio.** Serial0 terminates at a dead footprint. Replaced by the XIAO bridge. |
| **SW2** | CUS-3B SP3T slide switch | Proprietary footprint | No power switch — pads bridged on the "PC" position |
| **PL1** | 26-way dual header | Through-hole, costly on an SMD board | EEG input connector must be hand-soldered |

### 2.3 Key components (BOM extract)

| Ref | Part | Package | JLCPCB |
|---|---|---|---|
| U1 | LIS3DHTR accelerometer | LGA-16 | C15134 |
| U2 | SN74LVC1G32DCKR OR gate | SOT-353 | C7840 |
| U3 | LM2664M6 voltage inverter | SOT-23-6 | C108573 |
| U4 | TLV70025QDDCRQ1 LDO | SOT-23-5 | C19619 |
| U5 | MCP1754T-3302E/OT LDO | SOT-23-5 | C295712 |
| **U6** | **ADS1299IPAG** | **TQFP-64** | C476817 |
| **U7** | **PIC32MX250F128B** | **SSOP-28** | C1337166 |
| VR1 | TPS72325DBVR −2.5 V reg | SOT-23-5 | C69932 |
| X1 | ABMM2-8.000MHZ crystal | SMT | C431529 |
| D1 | LTST-C193TBKT blue LED | 0603 | C2290 |
| CONN1 | MicroSD slot | SMT | C91145 |

### 2.4 Tools used

| Tool | Purpose |
|---|---|
| **PICkit 3.5** | ICSP programming (5 wires — see §7.1) |
| **MPLAB X IPE v5.35** | Flashing the merged hex |
| **Arduino IDE 2.x** | Compiling Cyton firmware (chipKIT core) and XIAO sketch (ESP32 core) |
| **CP2102 USB-TTL** (3.3 V) | Independent serial monitor on D11/D12, `VID_10C4&PID_EA64` |
| **Seeed XIAO ESP32C3** | WiFi bridge, `VID_303A&PID_1001` |
| Multimeter | Continuity checks |

---

## 3. Source Repositories

Three upstream repositories, all public, all pinned. They sit under `vendor/` (and
`mechanical/` for the headset) and are **git-ignored** — nothing tracked in this repo
depends on them being present, and each can be restored with one command. Everything in
those trees that was *not* upstream — the regenerated Gerbers, the JLCPCB BOM and CPL,
the quotes — was lifted out into `hardware/` and is tracked here. See `VENDOR.md`.

| Path in this repo | Upstream | Pinned at | Role |
|---|---|---|---|
| `vendor/openbci-v3-hardware/` | `OpenBCI/V3_Hardware_Design_Files` | `6bce559` (2023-02-06) | Schematic, PCB, upstream Gerbers, BOM/CPL. Two files locally modified — §3.1 |
| `vendor/openbci-v3-hardware/OpenBCI_Cyton_Library/` | `OpenBCI/OpenBCI_Cyton_Library` | `24e1c42` (2025-07-24) | Cyton firmware, **v3.1.5** — what was flashed |
| `vendor/openbci-v3-hardware/PIC32-avrdude-bootloader/` | `chipKIT32/PIC32-avrdude-bootloader` | `95cf5d9` (2024-02-08) | chipKIT bootloader source + prebuilt hex |
| `mechanical/ultracortex-upstream/` | `OpenBCI/Ultracortex` | `338b52b` (2022-09-29) | Headset mechanicals. Only `Mark_IV` is checked out — §3.3 |

`vendor/PIC32-avrdude-bootloader-master/` and its zip are an older separate download of
the same bootloader, kept because the flashing was done from that copy.

> The two repos nested inside `vendor/openbci-v3-hardware/` are plain clones, **not
> submodules** — the parent sees them as untracked directories.

### 3.1 Local modifications to the hardware repo

Two tracked files differ from upstream. Both are copied into `hardware/`, so they
survive even if the clone is deleted:

| File in the clone | Change | Copy tracked here |
|---|---|---|
| `OpenBCI Cyton Designs/OpenBCI 32bit.pcb` | Re-saved from DesignSpark (360 KB → 395 KB) | `hardware/reference/OpenBCI 32bit.pcb` |
| `OBCI_Cyton_Plots/OBCI_V4_C (Component Positions CSV).csv` | Header rewritten to JLCPCB CPL format: `Name,Component,Side,Centre X,Centre Y,Rotation` → `Designator,Val,Layer,Mid X,Mid Y,Rotation` | `hardware/bom/CPL-OBCI_V4_C-jlcpcb-format.csv` |

Everything that was merely *untracked* in that clone now lives here as tracked files:

| Now at | Contents |
|---|---|
| `hardware/gerbers/` | The regenerated Gerber set (`OpenBCI 32bit - *.gbr`), both NC drill files, `OpenBCI 32bit.mop`, the plot report, `gerber.zip` — **the files the board was actually built from** |
| `hardware/bom/` | `Cyton_BOM_AutoMatch.csv`, `Cyton_BOM_Turnkey.csv`, `Cyton_PNP_Fixed_MM.csv`, `OBCI_BOM_JLCPCB.csv`, and the CPL above |
| `hardware/quotes/` | JLCPCB, Robu and LionCircuits quotes, plus the initial and final quote |
| `hardware/component-selection/` | The five "Component selection" PDFs, in revision order |
| `hardware/reference/` | `OBCI_V3_32bit-Schematic.jpg`, board photos, DesignSpark `.sch` / `.pcb` |

### 3.2 Key design files

| File | Notes |
|---|---|
| `hardware/reference/OBCI_V3_32bit-Schematic.jpg` | **The schematic.** 5037×3237 px. Everything in §4 was read from here. |
| `hardware/reference/OpenBCI 32bit.sch` | DesignSpark source |
| `hardware/bom/CPL-OBCI_V4_C-jlcpcb-format.csv` | Pick-and-place / component locations, JLCPCB header |

### 3.3 The Ultracortex clone, and what was deleted

`mechanical/ultracortex-upstream/` has an empty index against a populated HEAD, so
`git status` reports ~686 staged deletions and `git ls-files` returns nothing. Only
`Mark_IV` is checked out. One command restores every revision in the pack — `Mark_1`,
`Mark_2`, `Mark_3`, `Mark_III_Nova`, `Mark_III_Nova_REVISED`, `Mark_IV`:

```bash
git -C "C:/Users/abhij/Desktop/NeuroRehab/cyton-hardware/mechanical/ultracortex-upstream" reset --hard HEAD
```

**Deleted 1 October 2026** as verified duplicates, freeing 756 MB:

| Deleted | Size | Why it was safe |
|---|---|---|
| `Ultracortex2/` | 502 MB | `.git` only, same remote at the same commit `338b52b` |
| `Ultracortex_Downloaded/` | 175 MB | `Mark_1`–`Mark_3`, all present in the kept clone's HEAD tree |
| `Ultracortex.zip` | 79 MB | Zip of the same upstream repo |

`mechanical/a1-mini-prints/` is **not** upstream — those are the Bambu A1 Mini plates and
the Cyton case that were actually printed.

---

## 4. Schematic Reference

> Everything here was read directly from `OBCI_V3_32bit-Schematic.jpg`. **This section is the single most valuable output of the whole exercise** — the pin mapping is what unblocked the bring-up.

### 4.1 PIC32MX250F128B (U7) — complete pinout

SSOP-28, **top side**, CPL position (1321, 780), rotation 90°.

| Pin | chipKIT | Net | Function |
|---:|---|---|---|
| 1 | — | MCLR | Reset. Pull-up **R7 470 K**; **SW3** pulls to GND |
| 2 | D9 | DRDY | ADS1299 data-ready interrupt |
| 3 | D10 | MOSI | SPI |
| 4 | **D11** | **PGD** | **ICSP data + BLUE LED D1 (via R8 1 K) + Serial1 TX** |
| 5 | **D12** | **PGC** | **ICSP clock + Serial1 RX** |
| 6 | D13 | D13 | Broken out on J3-1 |
| 7 | **D14** | **TXD** | **Serial0 TX** → BLE1 pin 4 |
| 8 | — | GND | |
| 9 | D15 | — | X1 8 MHz crystal (C23 18 pF) |
| 10 | D16 | — | X1 8 MHz crystal (C20 18 pF) |
| 11 | **D17** | **BOOT_EN** | Bootloader program-enable. Pull-**down** **R9 470 K**; **SW1** pulls to DVDD |
| 12 | D18 | D18 | Broken out on J4-3 |
| 13 | — | Vdd | |
| 14 | D0 | INT1 | |
| 15 | — | Vbus | |
| 16 | D1 | CS4 | |
| 17 | D2 | CS3 | |
| 18 | D3 | CS2 | |
| 19 | — | GND | |
| 20 | — | Vcap | C25 10 µF |
| 21 | D4 | RESET | ADS1299 reset |
| 22 | D5 | MISO | SPI |
| 23 | — | Vdd | |
| 24 | **D6** | **RXD** | **Serial0 RX** ← BLE1 pin 3 |
| 25 | D7 | SCLK | SPI |
| 26 | D8 | CS1 | |
| 27 | — | GND | |
| 28 | — | Vdd | |

### 4.2 J3 / J4 — "CHIPKIT PIN BREAKOUT"

Two 4-pin headers, top side. **These are the only accessible digital breakouts on the board.**

| J3 | Signal | | J4 | Signal |
|---:|---|---|---:|---|
| 1 | D13 | | 1 | **BOOT_EN** |
| 2 | **PGC (D12)** | | 2 | **MCLR** |
| 3 | **DVDD** | | 3 | D18 |
| 4 | **AGND** | | 4 | **PGD (D11)** |

### 4.3 BLE1 (RFD22301) footprint — bottom side

**This is the finding that cost the most time.** The pads silkscreened `RFTX` / `RFRX` / `RFRESET` are **not** the PIC's UART.

| BLE1 pin | Module signal | Net | Reaches the PIC? |
|---:|---|---|---|
| 1, 2, 8, 9, 10, 12, 18, 19 | GND | AGND | — |
| **3** | GPIO2 | **RXD** | ✅ **PIC pin 24 (D6)** |
| **4** | GPIO3 | **TXD** | ✅ **PIC pin 7 (D14)** |
| 5 | GPIO4 | BLE Enable | via R11 470 K, D10 3 V zener, R10 10 K |
| 6 | GPIO5 | PGC | |
| 7 | GPIO6 | — | not connected |
| 11 | EXT ANT | — | not connected |
| 13 | 3V | DVDD | |
| 14 | RESET | RF_RESET | ❌ module only |
| 15 | FACTORY | — | not connected |
| **16** | GPIO0/AREF | **RF_RXD** | ❌ **module only** |
| **17** | GPIO1 | **RF_TXD** | ❌ **module only** |

> **`RF_TXD` / `RF_RXD` are the RFduino module's own serial port (its GPIO0/GPIO1), broken out so you can flash the radio.** They never touch the PIC32. With BLE1 unpopulated they are **dead traces terminating at an empty footprint.**

Schematic annotation on this block (an errata applied to the design):

```
Change R10 to D10 3V Zener CZRQR52C3-HF
Change R11 to 470K
Add R10 10K to drain Zener
```

### 4.4 The two UARTs

| | Serial0 (UART1) | Serial1 (UART2) |
|---|---|---|
| TX pin | D14 (RB3), PIC pin 7 | **D11 (RB0/PGED1), PIC pin 4** |
| RX pin | D6 (RB13), PIC pin 24 | **D12 (RB1/PGEC1), PIC pin 5** |
| Goes to | BLE1 pins 4/3 (empty footprint) | **J4-4 / J3-2 (accessible)** |
| Purpose | Radio link | Debug / "sniff mode" |
| Usable on this board | ❌ not physically reachable | ✅ **this is the one to use** |

From `chipkit-core/pic32/2.1.0/variants/openbci/Board_Defs.h`:

```c
#define _SER0_TX_OUT   PPS_OUT_U1TX
#define _SER0_TX_PIN   14      // RB3
#define _SER0_RX_IN    PPS_IN_U1RX
#define _SER0_RX_PIN   6       // RB13
#define _SER1_TX_OUT   PPS_OUT_U2TX
#define _SER1_TX_PIN   11      // RB0  PGED1
#define _SER1_RX_IN    PPS_IN_U2RX
#define _SER1_RX_PIN   12      // RB1  PGEC1
```

> ⚠️ **The library's own comment is stale.** `OpenBCI_32bit_Library.cpp` instructs you to edit `Board_Defs.h` lines 311/313 from `7`/`10` to `11`/`12`. **chipKIT core 2.1.0 already ships 11/12.** Do not edit it.

### 4.5 Other schematic blocks

| Block | Contents |
|---|---|
| **Power supply** | Battery connect → SW2 (SP3T) → RAW. Voltage inverter (LM2664), +3 V reg (MCP1700T-2502E/TT per notes / MCP1754), +2.5 V reg, −2.5 V reg (TPS72325). Generates AVDD/AVSS **±2.5 V for the ADS1299** |
| **ADS1299** | U6, 8 differential inputs with CAY16-F4 resistor arrays and TPD4E1B06 TVS arrays. BIAS_DRV, BIAS_INV, SRB1/SRB2 |
| **Accelerometer** | LIS3DH on SPI (CS4) |
| **SD card** | CONN1, `SD_SS` = chipKIT pin 2 |
| **Input connector** | PL1, EEG inputs 1N/1P…8N/8P, SRB, BIAS, AVDD/AVSS |
| **Daisy bus** | DVDD, MISO, MOSI, SCLK, RESET, PGC/PGD, CS2/CS3 |

### 4.6 Connector/switch positions (from CPL)

| Ref | Value | Side |
|---|---|---|
| J1 | PINHEAD-8 | Top |
| J2 | 2WP | Top |
| J3, J4 | 4WP | Top |
| PL1 | **26WDP** (26-way dual = 13×2) | Top |
| PL2 | SMT_QUAD_04 | Bottom |
| B1 | BATT | Bottom |
| SW2 | **CUS-3B SP3T SLIDE SWITCH** | Bottom |
| SW1, SW3 | SW_TACT (PTS810) | Top |
| BLE1 | RFD22301 | Bottom |
| CONN1 | SEEEDmicroSD | Bottom |

---

## 5. Firmware Reference

`OpenBCI_32bit_Library` **v3.1.5**, installed at `Documents/Arduino/libraries/OpenBCI_32bit_Library`.

Required companion libraries (all present):

| Library | Version | Provides |
|---|---|---|
| OpenBCI_32bit_Library | 3.1.5 | Core |
| OpenBCI_32bit_SD | 2.0.0 | `OBCI32_SD.h` |
| OpenBCI_Wifi_Master | 1.0.1 | `OpenBCI_Wifi_Master.h` |
| DSPI, EEPROM | (chipKIT core) | SPI, EEPROM |

### 5.1 `begin()` vs `beginDebug()` — the critical distinction

```c
void OpenBCI_32bit_Library::begin(void)          { boardBegin(); }
void OpenBCI_32bit_Library::beginDebug(void)     { beginDebug(OPENBCI_BAUD_RATE); }

boolean OpenBCI_32bit_Library::boardBegin(void) {
  beginPinsDefault();
  beginSerial0();
  delay(10);
  boardBeginADSInterrupt();
  boardReset();
  return true;
}

boolean OpenBCI_32bit_Library::boardBeginDebug(int baudRate) {
  beginPinsDebug();
  beginSerial0();
  beginSerial1(baudRate);
  curBoardMode = BOARD_MODE_DEBUG;
  curDebugMode = DEBUG_MODE_ON;
  boardBeginADSInterrupt();
  boardReset();
  return true;
}
```

**Pin configuration differs, and this matters physically:**

```c
void OpenBCI_32bit_Library::beginPinsDefault(void) {
  pinMode(OPENBCI_PIN_LED, OUTPUT);        // pin 11
  digitalWrite(OPENBCI_PIN_LED, HIGH);     // <-- LED SOLID ON
  pinMode(OPENBCI_PIN_PGC, OUTPUT);        // pin 12 driven as OUTPUT
}

void OpenBCI_32bit_Library::beginPinsDebug(void) {
  pinMode(OPENBCI_PIN_SERIAL1_TX, OUTPUT); // pin 11
  pinMode(OPENBCI_PIN_SERIAL1_RX, INPUT);  // pin 12 becomes INPUT
}
```

> ⚠️ In **default** mode the PIC **drives D12 as an output**. Connecting a serial adapter's TX to D12 in that mode causes contention. `beginDebug()` makes it an input. **Never attach a transmitter to D12 unless the firmware was built with `beginDebug()`.**

> 💡 **`beginPinsDefault()` turning the LED solid on is a free diagnostic** — see §11.1.

Both functions **always return `true`**, so the `Board up` / `Board err` branch is decorative — `Board err` can never print. It is not an ADS1299 health check.

### 5.2 Output mirroring

```c
void OpenBCI_32bit_Library::writeSerial(uint8_t c) {
  if (iSerial0.tx) Serial0.write(c);
  if (iSerial1.tx) Serial1.write(c);
}
```

In debug mode **every outgoing byte goes to both ports** — banner *and* streaming EEG data. `DefaultBoard.ino` also processes incoming commands from both:

```c
if (board.hasDataSerial1()) {
    char newChar = board.getCharSerial1();
    sdProcessChar(newChar);
    board.processChar(newChar);
}
```

**Consequence:** Serial1 (D11/D12) is a fully bidirectional substitute for the radio link. This is what makes the whole project work.

### 5.3 The boot banner

`boardReset()` runs at the end of both begin paths and prints **unprompted**, ~500 ms after every power-up or `v`:

```c
void OpenBCI_32bit_Library::boardReset(void) {
  initialize();                    // ADS + accelerometer + daisy
  delay(500);
  configureLeadOffDetection(LOFF_MAG_6NA, LOFF_FREQ_31p2HZ);
  printlnAll("OpenBCI V3 8-16 channel");
  printAll("On Board ADS1299 Device ID: 0x");
  printlnHex(ADS_getDeviceID(ON_BOARD));      // must read 0x3E
  if (daisyPresent) { ... }
  printAll("LIS3DH Device ID: 0x");
  printlnHex(LIS3DH_getDeviceID());           // 0x33
  printlnAll("Firmware: v3.1.2");
  sendEOT();                                   // "$$$"
  delay(5);
  wifi.reset();
}
```

> 🔑 **The board announces itself. You never send a command to get the banner.** Open your terminal *before* powering on, or you miss it. Assuming otherwise wasted weeks.
>
> 🔑 **`ADS_getDeviceID(ON_BOARD)` reading `0x3E` is the definitive proof the ADS1299 was soldered correctly.** It is a real SPI transaction against the chip.

### 5.4 Constants

```c
#define OPENBCI_BAUD_RATE                 115200
#define OPENBCI_BAUD_RATE_BLE               9600
#define OPENBCI_BAUD_RATE_MIN_NO_AVG      200000
#define OPENBCI_BOP                          'A'   // 0x41 — packet start
#define PCKT_START                          0xA0   // defined, NOT used for serial
#define PCKT_END                            0xC0
#define OPENBCI_PACKET_SIZE                   33
#define OPENBCI_SAMPLE_RATE_250              250
#define OPENBCI_SAMPLE_RATE_125              125
#define OPENBCI_NUMBER_BYTES_PER_ADS_SAMPLE   24
#define OPENBCI_NUMBER_OF_BYTES_AUX            6
#define OPENBCI_ADS_BYTES_PER_CHAN             3
#define OPENBCI_NUMBER_OF_CHANNELS_DEFAULT     8
#define OPENBCI_NUMBER_OF_CHANNELS_DAISY      16
#define OPENBCI_PIN_LED                       11
#define OPENBCI_PIN_PGC                       12
#define OPENBCI_PIN_SERIAL1_TX                11
#define OPENBCI_PIN_SERIAL1_RX                12
#define SD_SS                                  2
#define BLE_BYTES_PER_PACKET                  20
#define BLE_BYTES_PER_SAMPLE                   6
#define BLE_SAMPLES_PER_PACKET                 3
#define BLE_TOTAL_DATA_BYTES                  18
```

### 5.5 The high-baud no-average path

```c
boolean downsample = true;
if (iSerial0.tx == false && iSerial1.baudRate > OPENBCI_BAUD_RATE_MIN_NO_AVG)
    downsample = false;
```

`ADS_writeChannelDataNoAvgDaisy()` runs only when Serial1 exceeds 200000 baud with Serial0 TX disabled. **Relevant only with a Daisy (16-channel) board** — for 8 channels both paths write the same 24 bytes. Not used here.

### 5.6 Bootloader

`vendor/openbci-v3-hardware/PIC32-avrdude-bootloader/BootloadersCurrent-hex/**UDB32_MX2_DIP.hex**` — the Cyton's bootloader. Config lives under `_BOARD_UDB32_MX2_DIP_` in `bootloaders/configs/openbci.h`.

```c
#define CAPABILITIES (blCapBootLED | blCapDownloadLED | blCapUARTInterface \
                    | blCapProgramButton | blCapVirtualProgramButton | CAPCOMMON)
#define BLedLat  B      // Boot LED on PORTB
#define BLedBit  0      // bit 0 = RB0 = D11 = the blue LED
#define LedOn    Low
#define BntOn    High
```

Config bits:

```c
#pragma config FNOSC    = PRIPLL      // primary oscillator with PLL
#pragma config POSCMOD  = XT          // 8 MHz crystal
#pragma config FPLLIDIV = DIV_2
#pragma config FPLLMUL  = MUL_20
#pragma config FPLLODIV = DIV_2       // -> 40 MHz core
#pragma config FPBDIV   = DIV_1
#pragma config UPLLEN   = ON
#pragma config FWDTEN   = OFF
#pragma config JTAGEN   = OFF
#pragma config ICESEL   = ICS_PGx1    // ICSP channel 1 = PGED1/PGEC1
#pragma config CP       = OFF
```

**Key facts:**
- `blCapUARTInterface` — the bootloader uploads over **UART only**, no USB. On a stock Cyton that UART runs through the RFduino to the dongle. With BLE1 unpopulated, **bootloader uploads are impossible** — you must use ICSP.
- `blCapProgramButton` — **BOOT_EN (D17)** held high at reset keeps it in upload mode. R9 470 K pulls it low; SW1 pulls it high.
- The Boot LED is **RB0 = D11 = the blue LED = PGD**. See §11.1.
- `ICESEL = ICS_PGx1` confirms programming happens on PGED1/PGEC1 = D11/D12.

### 5.7 Memory map

| Region | Address range | Contents |
|---|---|---|
| Program flash | `0x1D0000F8 … 0x1D016AF3` | Application (our `beginDebug` build, ~92 KB) |
| Program flash | `0x1D0000F8 … 0x1D016A53` | *(stock reference build, for comparison)* |
| Boot flash | `0x1FC00000 … 0x1FC00BFF` | Bootloader (3072 bytes) |

No overlap — this is why bootloader and application merge cleanly into one hex.

---

## 6. Serial Protocol Reference

### 6.1 Packet format

**33 bytes, 250 packets/sec = 8250 bytes/sec.**

| Offset | Bytes | Content |
|---:|---:|---|
| 0 | 1 | **`0x41`** (`'A'`, `OPENBCI_BOP`) |
| 1 | 1 | Sample counter, wraps 0–255, +1 per packet |
| 2–25 | 24 | 8 channels × 3 bytes, **signed 24-bit big-endian** |
| 26–31 | 6 | Aux / accelerometer |
| 32 | 1 | Stop byte: `PCKT_END \| packetType` = **`0xC0`–`0xCF`** |

```c
writeSerial(OPENBCI_BOP);                          // 0x41
...
writeSerial((uint8_t)(PCKT_END | packetType));     // 0xC0..0xCF
```

> ⚠️ **The start byte is `0x41`, not `0xA0`.** Older OpenBCI documentation says `0xA0`, and `PCKT_START 0xA0` *is* defined in the header — but `sendChannelData()` writes `OPENBCI_BOP` = `'A'` = `0x41`. Verified empirically and in source. A parser looking for `0xA0` will never sync.
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

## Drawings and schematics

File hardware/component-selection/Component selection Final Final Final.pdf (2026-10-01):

PCB | Bill of Materials | Component Placements | Quote & Order

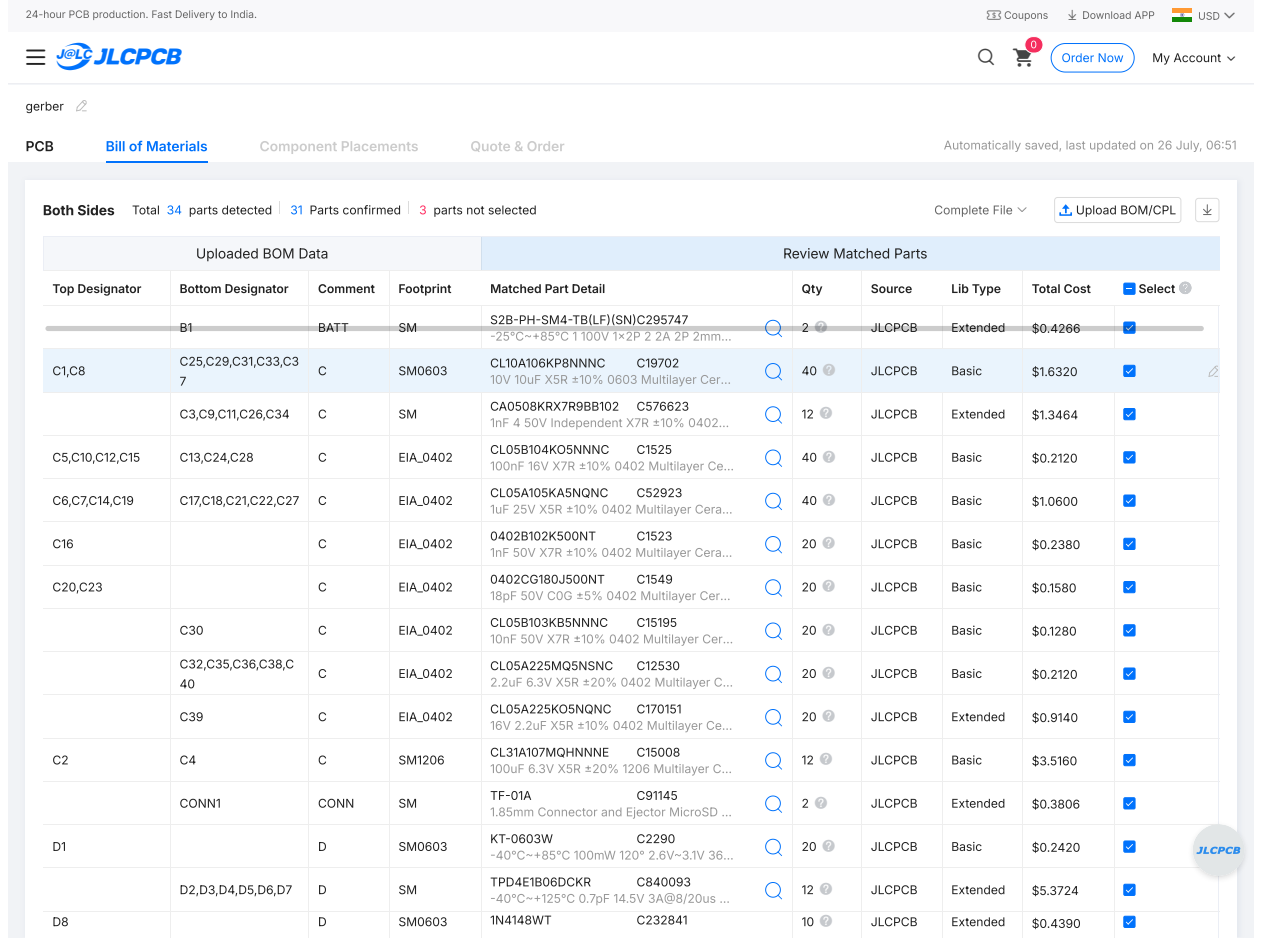
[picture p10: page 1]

Automatically saved, last updated on 26 July, 06:51

1.85mm Connector and Ejector MicroSD …

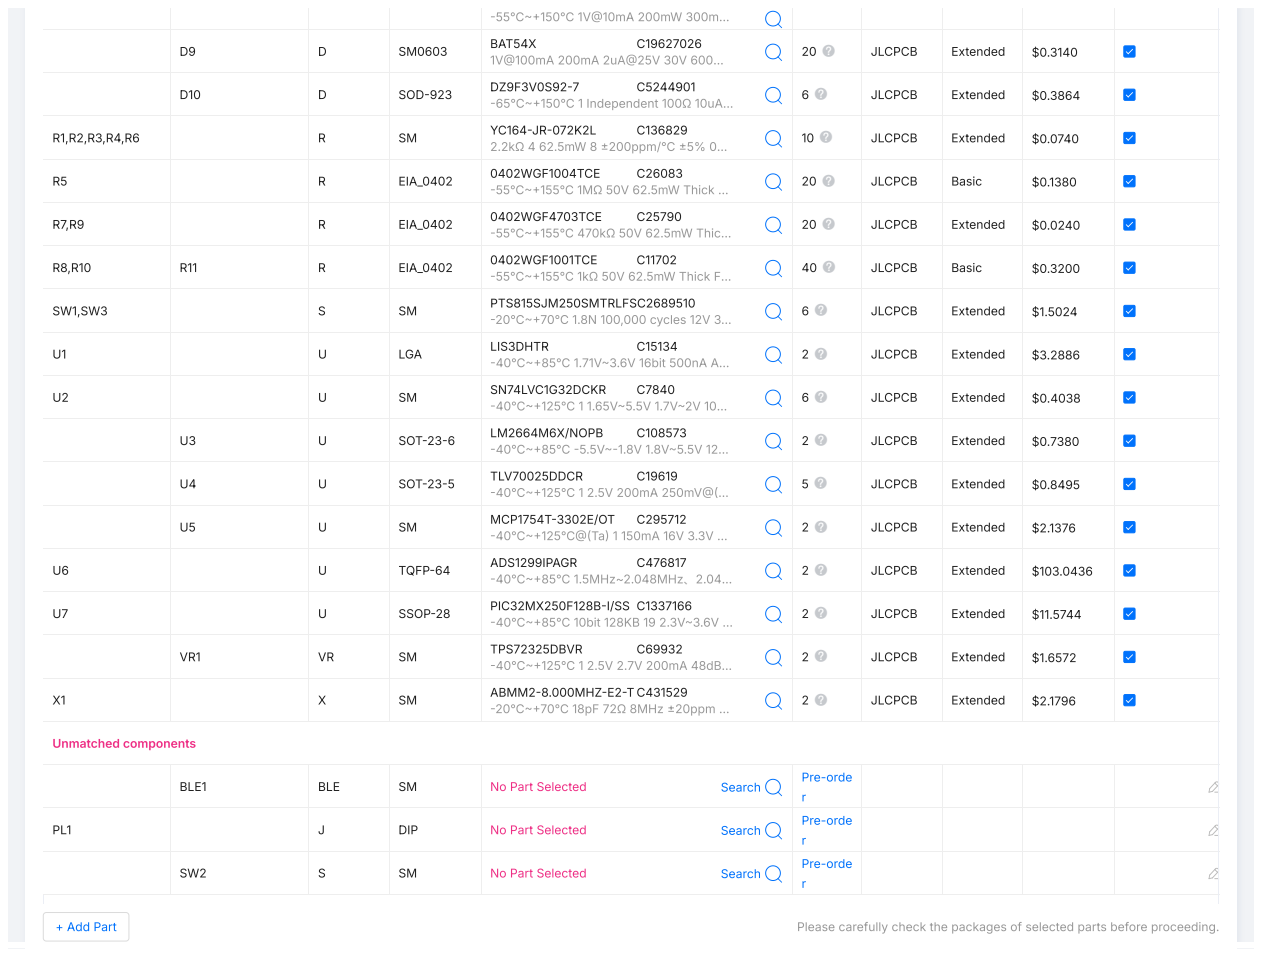
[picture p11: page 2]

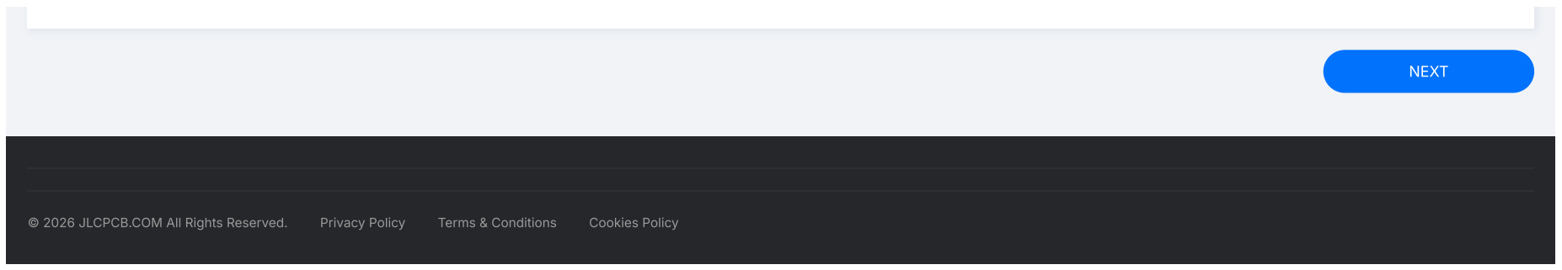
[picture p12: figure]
NEXT

© 2026 JLCPCB.COM All Rights Reserved. | Privacy Policy (https://jlcpcb.com/help/article/Privacy-Policy) | Terms & Conditions (https://jlcpcb.com/help/article/Terms-%26-Conditions) | Cookies Policy (https://jlcpcb.com/help/article/JLCPCB-Cookie-Notice)

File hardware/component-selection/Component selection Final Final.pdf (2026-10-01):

PCB | Bill of Materials | Component Placements | Quote & Order

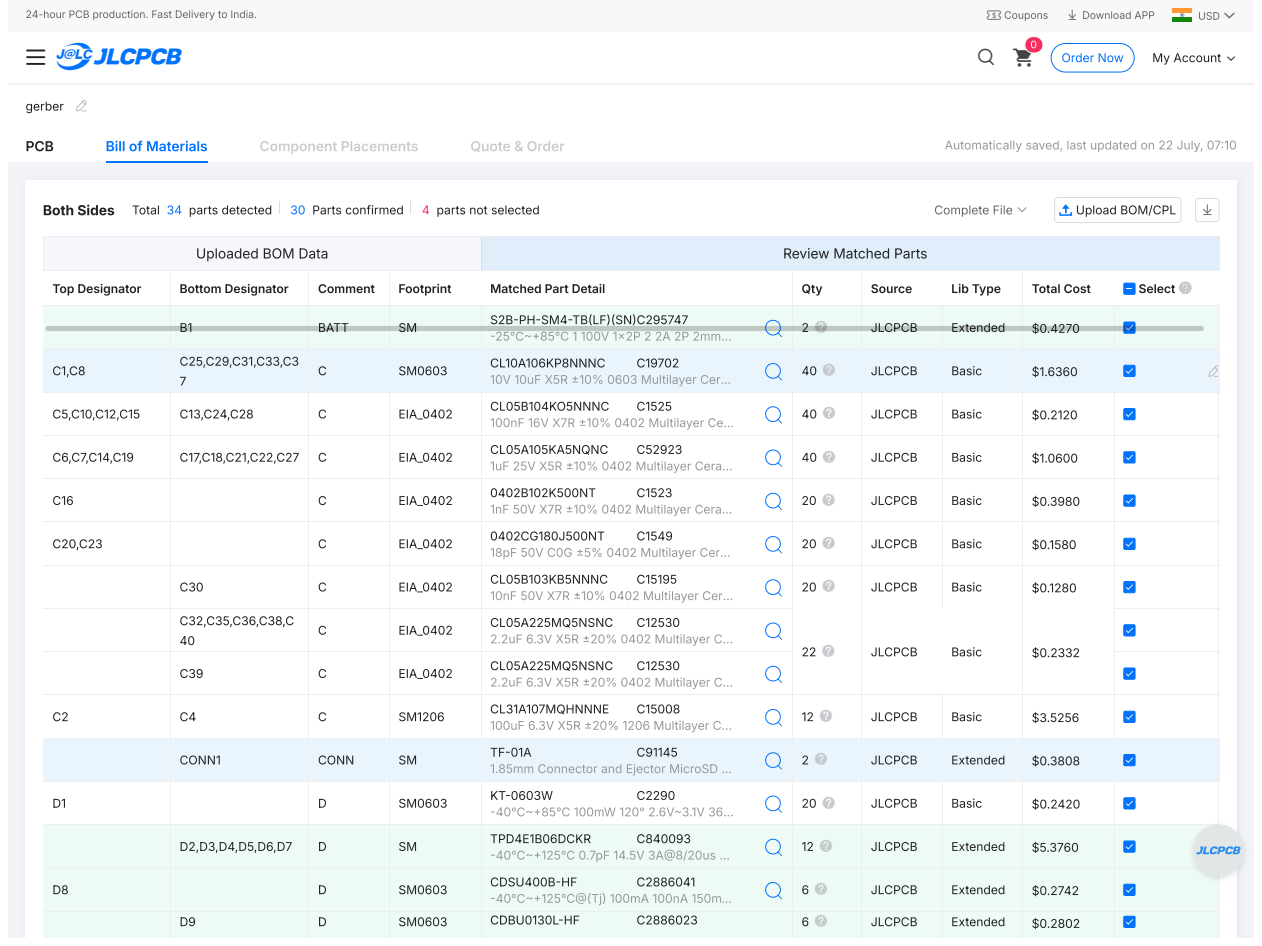
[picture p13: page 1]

Automatically saved, last updated on 22 July, 07:10

1.85mm Connector and Ejector MicroSD …

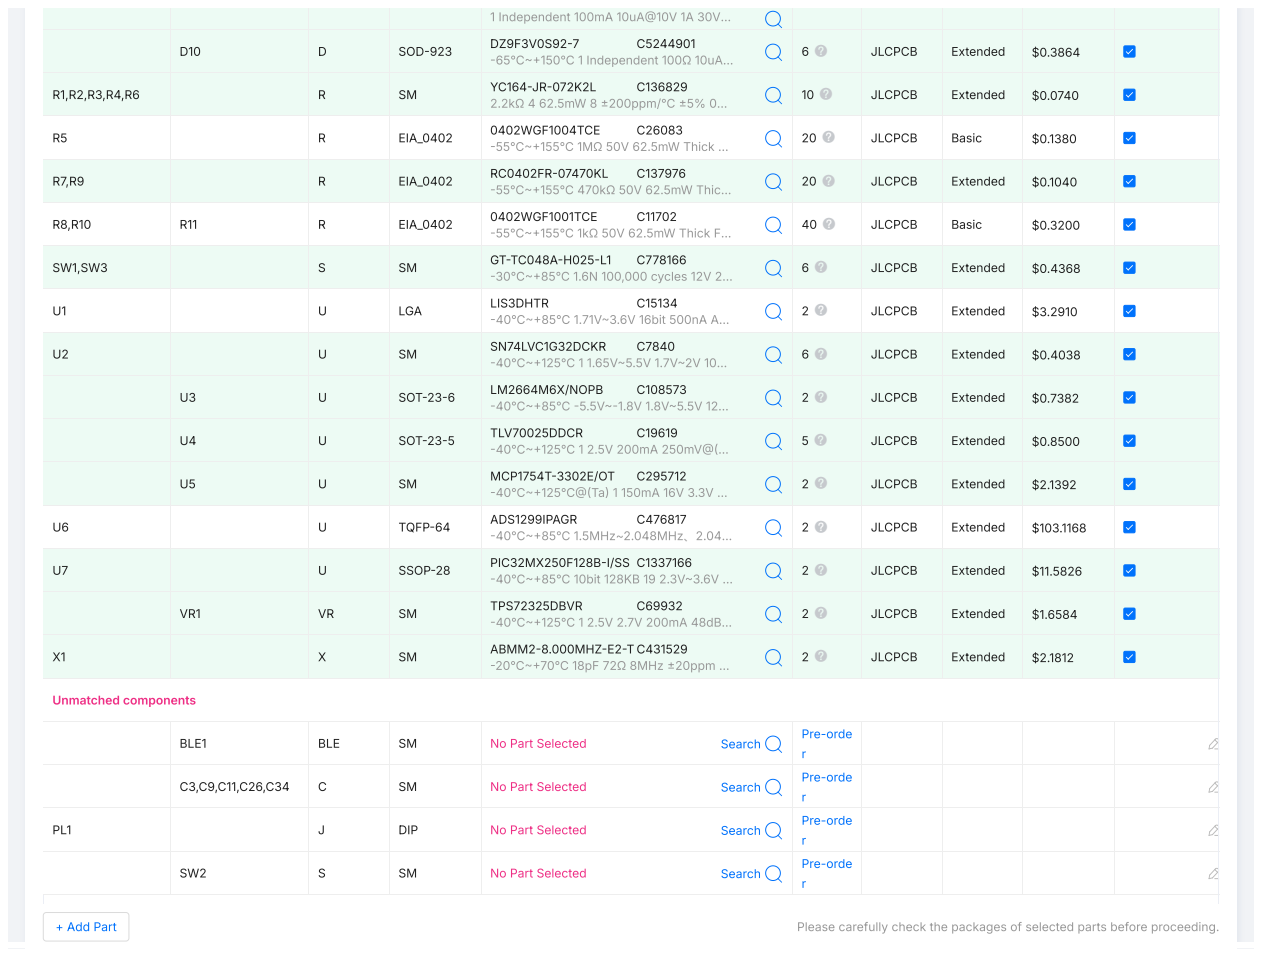
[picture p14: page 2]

NEXT

© 2026 JLCPCB.COM All Rights Reserved. | Privacy Policy (https://jlcpcb.com/help/article/Privacy-Policy) | Terms & Conditions (https://jlcpcb.com/help/article/Terms-%26-Conditions) | Cookies Policy (https://jlcpcb.com/help/article/JLCPCB-Cookie-Notice)

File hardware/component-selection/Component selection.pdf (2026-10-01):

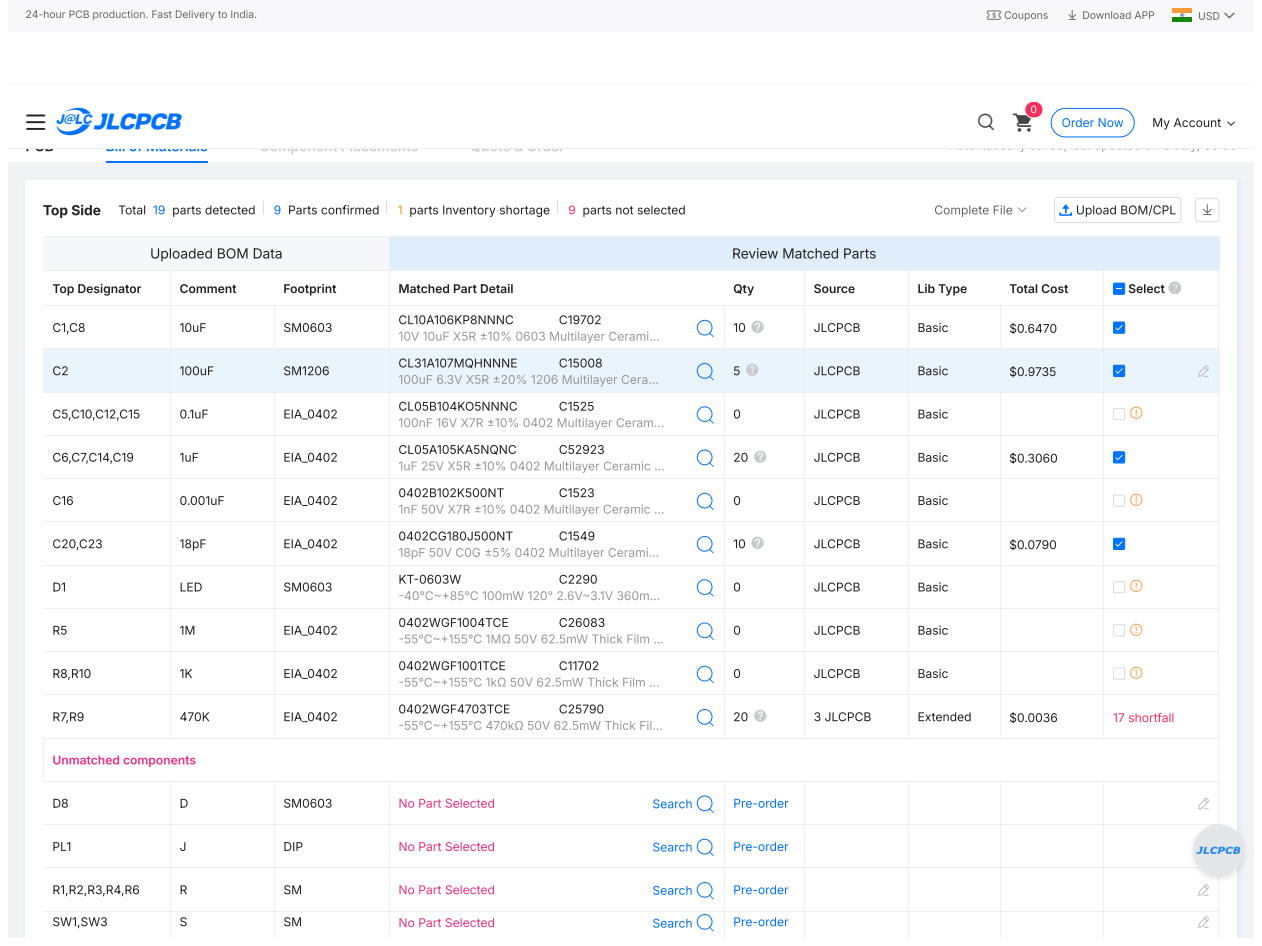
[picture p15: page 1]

Automatically saved, last updated on 3 July, 05:05

Uploaded BOM Data | Review Matched Parts

Top Designator | Comment | Footprint | Matched Part Detail | Qty | Source | Lib Type | Total Cost | Select

C1,C8 | 10uF | SM0603 | CL10A106KP8NNNC C19702 10V 10uF X5R ±10% 0603 Multilayer Cerami… | 10 | JLCPCB | Basic | $0.6470

C2 | 100uF | SM1206 | CL31A107MQHNNNE C15008 100uF 6.3V X5R ±20% 1206 Multilayer Cera… | 5 | JLCPCB | Basic | $0.9735

C5,C10,C12,C15 | 0.1uF | EIA_0402 | CL05B104KO5NNNC C1525 100nF 16V X7R ±10% 0402 Multilayer Ceram… | 0 | JLCPCB | Basic

C6,C7,C14,C19 | 1uF | EIA_0402 | CL05A105KA5NQNC C52923 1uF 25V X5R ±10% 0402 Multilayer Ceramic … | 20 | JLCPCB | Basic | $0.3060

C16 | 0.001uF | EIA_0402 | 0402B102K500NT C1523 1nF 50V X7R ±10% 0402 Multilayer Ceramic … | 0 | JLCPCB | Basic

C20,C23 | 18pF | EIA_0402 | 0402CG180J500NT C1549 18pF 50V C0G ±5% 0402 Multilayer Cerami… | 10 | JLCPCB | Basic | $0.0790

D1 | LED | SM0603 | KT-0603W C2290 -40℃~+85℃ 100mW 120° 2.6V~3.1V 360m… | 0 | JLCPCB | Basic

R5 | 1M | EIA_0402 | 0402WGF1004TCE C26083 -55℃~+155℃ 1MΩ 50V 62.5mW Thick Film … | 0 | JLCPCB | Basic

R8,R10 | 1K | EIA_0402 | 0402WGF1001TCE C11702 -55℃~+155℃ 1kΩ 50V 62.5mW Thick Film … | 0 | JLCPCB | Basic

R7,R9 | 470K | EIA_0402 | 0402WGF4703TCE C25790 -55℃~+155℃ 470kΩ 50V 62.5mW Thick Fil… | 20 | 3 JLCPCB | Extended | $0.0036 | 17 shortfall

D8 | D | SM0603 | No Part Selected Search | Pre-order

PL1 | J | DIP | No Part Selected Search | Pre-order

R1,R2,R3,R4,R6 | R | SM | No Part Selected Search | Pre-order

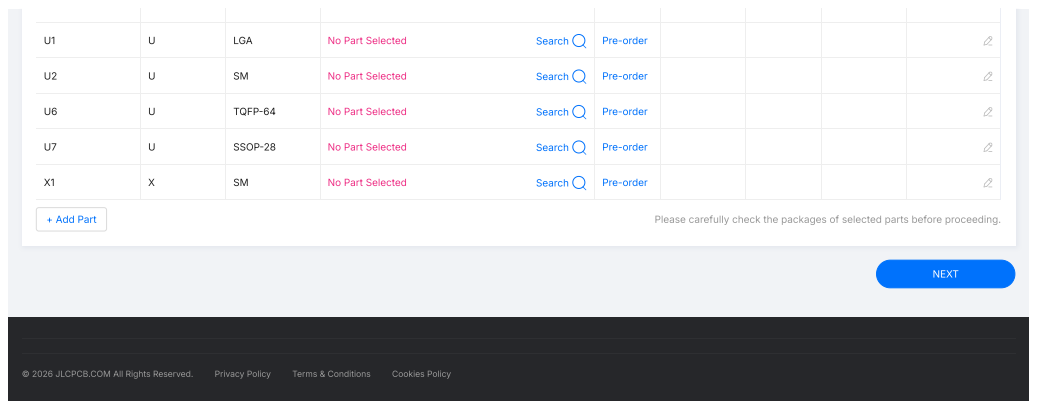
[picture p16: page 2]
© 2026 JLCPCB.COM All Rights Reserved.; Privacy Policy; Terms & Conditions; Cookies Policy; + Add Part; Please carefully check the packages of selected parts before proceeding.; NEXT

U1 | U | LGA | No Part Selected Search | Pre-order

U2 | U | SM | No Part Selected Search | Pre-order

U6 | U | TQFP-64 | No Part Selected Search | Pre-order

U7 | U | SSOP-28 | No Part Selected Search | Pre-order

X1 | X | SM | No Part Selected Search | Pre-order

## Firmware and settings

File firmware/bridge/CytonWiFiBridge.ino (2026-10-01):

/* ===========================================================================
 * CytonWiFiBridge
 *
 * Seeed XIAO ESP32C3 acting as the wireless link for an OpenBCI Cyton whose
 * RFD22301 radio (BLE1) was never populated.
 *
 *      Cyton  <--UART 115200-->  XIAO ESP32C3  <--WiFi TCP-->  PC
 *
 * ---------------------------------------------------------------------------
 * WIRING - 3.3V both sides, no level shifting required
 * ---------------------------------------------------------------------------
 *   Cyton D11  (J4 pin 4)   ->  XIAO D1 / GPIO3     Cyton transmits
 *   Cyton D12  (J3 pin 2)   <-  XIAO D2 / GPIO4     Cyton receives
 *   Cyton AGND (J3 pin 4)   <-> XIAO GND            required
 *
 * A USB-TTL adapter may share D11 (its RX only) as an independent monitor.
 * Two receivers on one transmit line is fine. Never put two transmitters on
 * D12 - only the XIAO drives that pin.
 *
 * ---------------------------------------------------------------------------
 * WHY D11/D12 AND NOT THE "RFTX"/"RFRX" PADS
 * ---------------------------------------------------------------------------
 * The pads silkscreened RFTX / RFRX / RFRESET are a breakout for the RFduino
 * module's OWN serial port (module GPIO0/GPIO1), provided so you can flash the
 * radio. They never connect to the PIC32. With BLE1 unpopulated they are dead
 * traces, and a UART attached to them decodes ambient noise into ~225 junk
 * bytes/sec.
 *
 * The PIC's Serial0 reaches only BLE1 pins 3/4, which are unreachable module
 * pads. But firmware built with board.beginDebug() mirrors every outgoing byte
 * to Serial1 as well - including the streaming EEG data - and processes
 * incoming commands from Serial1. Serial1 is D11/D12, on the accessible J3/J4
 * headers. So the debug port is a fully bidirectional substitute.
 *
 * REQUIRES Cyton firmware built with board.beginDebug() (not board.begin()).
 *
 * ---------------------------------------------------------------------------
 * ARDUINO IDE SETTINGS
 * ---------------------------------------------------------------------------
 *   Board:            XIAO_ESP32C3
 *   USB CDC On Boot:  ENABLED        <-- required
 *
 * With CDC disabled, `Serial` falls back to UART0 on GPIO20/21 (silkscreen
 * D6/D7) and collides with anything else placed there. GPIO2, GPIO8 and GPIO9
 * are strapping pins and are avoided.
 *
 * Close the Serial Monitor before every upload - the ESP32C3's USB port is
 * generated by the chip itself and re-enumerates on reset, so a monitor
 * holding the old handle blocks the upload.
 *
 * ---------------------------------------------------------------------------
 * NETWORK MODES  (set USE_SOFTAP below)
 * ---------------------------------------------------------------------------
 * USE_SOFTAP 1 - ACCESS POINT (default, recommended for a portable rig)
 *   The XIAO creates its own WiFi network. Your laptop joins it directly, so
 *   there is no router in the path: same address every boot, strongest
 *   possible signal, lowest latency, and it works in a clinic or lab with no
 *   WiFi at all. Cost: the laptop has no internet while connected.
 *
 *     join SSID "CytonBridge" / pass "neurorehab", then connect to
 *     192.168.4.1:3000
 *
 * USE_SOFTAP 0 - STATION
 *   The XIAO joins an existing network and gets an address from DHCP (or a
 *   fixed one via USE_STATIC_IP). Convenient at a desk, but signal strength
 *   is whatever the room gives you - below about -80 dBm this link starts
 *   losing samples, and at 8250 B/s that shows up as gaps in the EEG.
 *
 * ---------------------------------------------------------------------------
 * COMMANDS  (type into Serial Monitor, or send over the TCP socket)
 * ---------------------------------------------------------------------------
 *   b  start streaming EEG        s  stop streaming
 *   v  soft reset (re-sends the boot banner)
 *   ?  dump register settings
 *
 * Test signals - useful before you own electrodes. With open inputs every
 * channel rails at 0x800000; these drive known waveforms through the ADS1299
 * so you can prove the analog front end works:
 *   0  connect all channels to ground (measures noise floor)
 *   -  1x amplitude square wave, slow      =  1x fast
 *   [  2x amplitude square wave, slow      ]  2x fast
 *   p  connect to DC
 *
 * Healthy stream: 33 bytes x 250 Hz = ~8250 B/s and ~250 packets/sec.
 * =========================================================================== */

#include <WiFi.h>

// ---------------------------------------------------------------- settings --

// 1 = ACCESS POINT. The XIAO creates its own network and your laptop joins it
//     directly. No router involved: fixed address every time, best signal,
//     works anywhere. Your laptop loses internet while connected.
// 0 = STATION. The XIAO joins your existing WiFi.
#define USE_SOFTAP 1

// -- access point mode (USE_SOFTAP 1) --
const char *AP_SSID    = "CytonBridge";
const char *AP_PASS    = "neurorehab";     // must be >= 8 chars for WPA2
const uint8_t AP_CHAN  = 6;                // 1, 6 or 11 are non-overlapping
// The bridge is always at 192.168.4.1 in this mode.

// -- station mode (USE_SOFTAP 0) --
const char *WIFI_SSID  = "Abhijith-2.4";
const char *WIFI_PASS  = "YOUR_WIFI_PASSWORD";

// Optional fixed address in station mode, so the bridge lands on the same IP
// every boot. Pick something above your router's DHCP pool.
// #define USE_STATIC_IP
#ifdef USE_STATIC_IP
static IPAddress STATIC_IP (192, 168, 1, 200);
static IPAddress GATEWAY   (192, 168, 1, 1);
static IPAddress SUBNET    (255, 255, 255, 0);
static IPAddress DNS_SRV   (192, 168, 1, 1);
#endif

const uint16_t TCP_PORT = 3000;

#define CYTON_RX_PIN 3        // XIAO D1 <- Cyton D11
#define CYTON_TX_PIN 4        // XIAO D2 -> Cyton D12
#define CYTON_BAUD   115200

#define SHOW_PREVIEW 1        // 1 = print a hex/ASCII sample each second
// -----------------------------------------------------------------------------

WiFiServer server(TCP_PORT);
WiFiClient client;

static uint8_t  buf[1024];
static uint32_t rxBytes  = 0;      // bytes this second
static uint32_t lastTick = 0;

// OpenBCI packet framing, confirmed against library v3.1.5:
//   writeSerial(OPENBCI_BOP)                 -> 0x41 ('A'), NOT the 0xA0 the
//                                               older OpenBCI docs describe
//   sample counter                           -> 1 byte
//   8 channels x 3 bytes                     -> 24 bytes
//   aux                                      -> 6 bytes
//   writeSerial(PCKT_END | packetType)       -> 0xC0..0xCF
//                                            = 33 bytes total
// Tracking this turns "some bytes arrived" into a real integrity measure.
#define OPENBCI_START_BYTE 0x41

static int      pktPos  = -1;      // -1 = hunting for the start byte
static uint32_t pktGood = 0;
static uint32_t pktBad  = 0;

#if SHOW_PREVIEW
static uint8_t preview[24];
static int     previewLen = 0;
#endif

// -----------------------------------------------------------------------------

static void trackPacket(uint8_t b) {
  if (pktPos < 0) {
    if (b == OPENBCI_START_BYTE) pktPos = 0;   // possible start of packet
  } else {
    pktPos++;
    if (pktPos == 32) {                  // 33rd byte is the stop byte
      if ((b & 0xF0) == 0xC0) pktGood++; else pktBad++;
      pktPos = -1;
    }
  }
}

static void startNetwork() {
#if USE_SOFTAP
  WiFi.mode(WIFI_AP);
  WiFi.setSleep(false);                  // keep latency low for realtime use

  if (!WiFi.softAP(AP_SSID, AP_PASS, AP_CHAN)) {
    Serial.println("ERROR: could not start access point");
    return;
  }
  Serial.println("Access point up. On your laptop, join:");
  Serial.printf ("  SSID:     %s\n", AP_SSID);
  Serial.printf ("  Password: %s\n", AP_PASS);
  Serial.print  ("  Bridge:   ");
  Serial.print  (WiFi.softAPIP());       // always 192.168.4.1
  Serial.printf (":%u\n", TCP_PORT);
  Serial.printf ("  Channel:  %u\n", AP_CHAN);
#else
#ifdef USE_STATIC_IP
  if (!WiFi.config(STATIC_IP, GATEWAY, SUBNET, DNS_SRV)) {
    Serial.println("WARNING: static IP config failed, falling back to DHCP");
  }
#endif
  WiFi.mode(WIFI_STA);
  WiFi.setSleep(false);
  WiFi.begin(WIFI_SSID, WIFI_PASS);

  Serial.printf("Joining \"%s\"", WIFI_SSID);
  while (WiFi.status() != WL_CONNECTED) {
    delay(250);
    Serial.print(".");
  }
  Serial.println();
  Serial.print  ("  IP:   ");
  Serial.print  (WiFi.localIP());
  Serial.printf (":%u\n", TCP_PORT);
  Serial.printf ("  RSSI: %d dBm   (weaker than -80 will drop samples)\n",
                 WiFi.RSSI());
#endif
}

static void printReport() {
  Serial.printf("[%5lu B/s | %3lu pkt/s", (unsigned long)rxBytes,
                (unsigned long)pktGood);
  if (pktBad) Serial.printf(" | %lu BAD", (unsigned long)pktBad);
  Serial.print(client && client.connected() ? " | client] " : " | no client] ");

#if SHOW_PREVIEW
  for (int i = 0; i < previewLen; i++) Serial.printf("%02X ", preview[i]);
  Serial.print("|");
  for (int i = 0; i < previewLen; i++) {
    char c = (char)preview[i];
    Serial.print((c >= 32 && c < 127) ? c : '.');
  }
  Serial.print("|");
#endif
  Serial.println();
}

// -----------------------------------------------------------------------------

void setup() {
  Serial.begin(115200);                  // USB CDC console
  delay(300);

  // Enlarge the UART receive buffer BEFORE begin(). The 256-byte default is
  // only ~31 ms of headroom at 8250 B/s.
  Serial1.setRxBufferSize(4096);
  Serial1.begin(CYTON_BAUD, SERIAL_8N1, CYTON_RX_PIN, CYTON_TX_PIN);

  Serial.println("\n=== CytonWiFiBridge ===");
  Serial.printf("UART  RX=GPIO%d (<-Cyton D11)  TX=GPIO%d (->Cyton D12)  @%d\n",
                CYTON_RX_PIN, CYTON_TX_PIN, CYTON_BAUD);

  startNetwork();

  server.begin();
  server.setNoDelay(true);               // no Nagle buffering on a realtime link

  Serial.println("Ready. Commands: b=stream  s=stop  v=reset  ?=registers");
  Serial.println("Waiting for a TCP client...");
}

void loop() {
  // -- accept a client, notice when one leaves --------------------------------
  if (!client || !client.connected()) {
    if (client) {
      client.stop();
      Serial.println("Client disconnected.");
    }
    WiFiClient incoming = server.available();
    if (incoming) {
      client = incoming;
      client.setNoDelay(true);
      Serial.print("Client connected: ");
      Serial.println(client.remoteIP());
    }
  }

  // -- Cyton -> network -------------------------------------------------------
  int avail = Serial1.available();
  if (avail > 0) {
    if (avail > (int)sizeof(buf)) avail = sizeof(buf);
    int got = Serial1.readBytes(buf, avail);
    rxBytes += got;

    for (int i = 0; i < got; i++) {
      trackPacket(buf[i]);
#if SHOW_PREVIEW
      if (previewLen < (int)sizeof(preview)) preview[previewLen++] = buf[i];
#endif
    }

    if (client && client.connected()) client.write(buf, got);
  }

  // -- network -> Cyton -------------------------------------------------------
  if (client && client.connected()) {
    while (client.available()) Serial1.write((uint8_t)client.read());
  }

  // -- USB console -> Cyton (type commands by hand) ---------------------------
  while (Serial.available()) Serial1.write((uint8_t)Serial.read());

  // -- once-per-second status -------------------------------------------------
  uint32_t now = millis();
  if (now - lastTick >= 1000) {
    if (rxBytes > 0) printReport();
    rxBytes = 0;
    pktGood = 0;
    pktBad  = 0;
#if SHOW_PREVIEW
    previewLen = 0;
#endif
    lastTick = now;
  }
}

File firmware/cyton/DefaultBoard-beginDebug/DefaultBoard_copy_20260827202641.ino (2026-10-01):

#include <DSPI.h>
#include <OBCI32_SD.h>
#include <EEPROM.h>
#include <OpenBCI_Wifi_Master_Definitions.h>
#include <OpenBCI_Wifi_Master.h>
#include <OpenBCI_32bit_Library.h>
#include <OpenBCI_32bit_Library_Definitions.h>


// Booleans Required for SD_Card_Stuff.ino
boolean addAccelToSD = false; // On writeDataToSDcard() call adds Accel data to SD card write
boolean addAuxToSD = false; // On writeDataToSDCard() call adds Aux data to SD card write
boolean SDfileOpen = false; // Set true by SD_Card_Stuff.ino on successful file open

void setup() {
  // Bring up the OpenBCI Board
  board.beginDebug();

  // Bring up wifi
  wifi.begin(true, true);


}

void loop() {
  if (board.streaming) {
    if (board.channelDataAvailable) {
      // Read from the ADS(s), store data, set channelDataAvailable flag to false
      board.updateChannelData();

      // Check to see if accel has new data
      if (board.curAccelMode == board.ACCEL_MODE_ON) {
        if(board.accelHasNewData()) {
          // Get new accel data
          board.accelUpdateAxisData();

          // Tell the SD_Card_Stuff.ino to add accel data in the next write to SD
          addAccelToSD = true; // Set false after writeDataToSDcard()
        }
      } else {
        addAuxToSD = true;
      }

      // Verify the SD file is open
      if(SDfileOpen) {
        // Write to the SD card, writes aux data
        writeDataToSDcard(board.sampleCounter);
      }

      board.sendChannelData();
    }
  }

  // Check serial 0 for new data
  if (board.hasDataSerial0()) {
    // Read one char from the serial 0 port
    char newChar = board.getCharSerial0();

    // Send to the sd library for processing
    sdProcessChar(newChar);

    // Send to the board library
    board.processChar(newChar);
  }

  if (board.hasDataSerial1()) {
    // Read one char from the serial 1 port
    char newChar = board.getCharSerial1();

    // Send to the sd library for processing
    sdProcessChar(newChar);

    // Read one char and process it
    board.processChar(newChar);
  }

  // Call the loop function on the board
  board.loop();

  // Call to wifi loop
  wifi.loop();

  if (wifi.hasData()) {
    // Read one char from the wifi shield
    char newChar = wifi.getChar();

    // Send to the sd library for processing
    sdProcessChar(newChar);

    // Send to the board library
    board.processCharWifi(newChar);
  }

  if (!wifi.sentGains) {
    if(wifi.present && wifi.tx) {
      wifi.sendGains(board.numChannels, board.getGains());
    }
  }
}

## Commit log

2026-10-01 Consolidate the Cyton hardware record into one repo
    Everything related to the self-fabricated OpenBCI Cyton, moved out of the
    NeuroRehab root into cyton-hardware/: the bring-up document, wiring and
    electrode notes, the flashable images, the exact beginDebug sketch, the XIAO
    bridge firmware, the Flask/Python stack with its recordings, and the JLCPCB
    order artifacts (BOM, CPL, regenerated Gerbers, quotes).
    Files are at their original contents in this commit; the bring-up document
    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
    [Cyton_BOM_AutoMatch.csv, Cyton_BOM_Turnkey.csv, Cyton_PNP_Fixed_MM.csv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]
2026-10-01 Rewrite the bring-up doc for this layout; add README and VENDOR
    CYTON_BRINGUP.md: every path now points at a real file in this repo. The
    merge-hex and listen-cyton commands, the bootloader hex, the sketch location
    and the server command were all rewritten, and a "Where everything lives"
    section maps the folders.
    Corrected what had gone stale since August:
    - Section 3 rewritten for vendor/ and mechanical/, with what was deleted and
    why it was safe.
    - Section 9 line counts were wrong (cyton_server.py 296 -> 453, index.html
    295 -> 415) and two files were missing entirely (cyton_experiments.py,
    fake_bridge.py). The REST table lacked /api/experiments and /api/experiment,
    and the CSV form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
    [OpenBCI 32bit - Board Outline.gbr, OpenBCI 32bit - Bottom Copper.gbr, OpenBCI 32bit - Bottom Paste Mask.gbr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]
